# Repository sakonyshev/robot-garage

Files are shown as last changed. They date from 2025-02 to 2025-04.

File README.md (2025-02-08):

# Automatic Vacuum Cleaner Robot Garage  

## Overview  
This project was inspired by the challenge of limited space in an apartment. Dedicating a full square meter of floor space for a robot vacuum’s parking spot seemed inefficient. Instead, the idea was to create a niche under the kitchen cabinets where the robot could park and charge.  

Work

## Features  
- Designed to fit under kitchen cabinets  
- Automatic door mechanism to enclose the robot when parked  
- Provides a dedicated charging space  

## Disclaimer  
⚠ **This is an early-stage, untested prototype.** Any modifications, builds, or implementations based on this project are done **at your own risk**. At the moment, the code only handles opening the door and closing it when the robot returns. The logic is as simple as possible, but the board's capabilities can be expanded. There is an additional slot for an extra sensor. The NodeMCU board has built-in Wi-Fi, so you can set up integration with your server or a virtual assistant such as Alice, Siri, etc.

## Installation & Assembly  
1. **Build the garage frame**  
   - Construct a housing that fits under your kitchen cabinets and accommodates your specific robot vacuum.  
   - Dimensions are **not provided**, as different robot models require different clearance and space. Ensure there is enough room for smooth docking and undocking.  

2. **Add the control board**
   - Prepare **[control board](pcb/board.dip)** based on **NodeMCU** to handle the opening and closing of the garage door. 
   - PCB
   - The control board will manage the door mechanism and control the motor based on signals, such as when the robot leaves and enters the garage.  

3. **Print and install the door mechanism**  
   - Download and 3D print the **gear assembly** responsible for opening and closing the garage door.  
   - The mechanism should be mounted on the **front left wall** of the garage.  
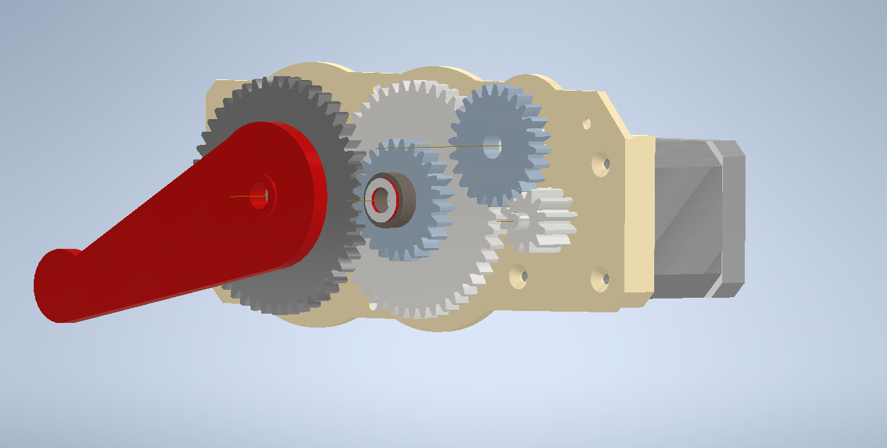
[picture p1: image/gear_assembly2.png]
Gear Assembly
   -   

4. **Install the door panel**  
   - Use a **standard chipboard (DSP) panel** as the door.  
   - Cut it to fit the gap between the **floor and kitchen cabinets**.
   - To create an opening mechanism, use the smallest and simplest hinges that fit your specific setup. Choose compact hinges that provide smooth movement while maintaining durability.
   - Ensure the panel moves freely with the installed gear mechanism.
   -  lift_mechanism

5. **Set up the charging station**  
   - Place the charging dock inside the garage.  
   - Ensure the robot can autonomously navigate into the garage and connect to the charger.

6. **Install a force resistor for docking detection**  
   - Attach a **resistor with variable resistance** to the floor under the robot’s wheel.  
   - The resistor should change its resistance when pressure is applied (i.e., when the robot returns to the base).  
   - This will allow the control board to detect when the robot is properly parked and the garage door can be closed.  

## Components  
- NodeMCU  
- NEMA17 stepper motor
- DRV8825 stepper motor driver
- Optocoupler EL817
- Force resistor 10kOm
- Resistors 10kOm and 260Om
- Linear Voltage Regulator L7805CV
- MOSFET Transistor IRLZ34N
- Capacitors 470mF, 0.1mF, 0.33mF
- Connectors KF301-2P
- Breakable Pin Headers
- Dip 3p toggle switch (or you may use wire jumpers instead)
- 12V power supply

## Connectors and Power Supply
The board has several connectors used for connecting peripheral sensors, a motor, and power supply.

- VCC_IN – Power input for the board. I used a 12V power adapter from an old router, but technically, any power supply up to 24V can be used. I recommend checking the datasheets of the components before using a different power source. Also, pay attention to potential heating of electronic components—heat sinks may need to be installed.
- POWER_SW – A connector for end-stop switch that supplies power to the board when activated.
- SPARE_SOCKET – Additional socket for connecting peripherals. For more details, refer to the schematic. It includes a control pin, a 3V pin, and ground.
- START_POS_SW – Output for the limit switch used to calibrate the initial position of the stepper motor.
- RES_IN – Connector for a resistor that changes its resistance depending on the applied pressure.
- J4 – Connector for connecting the stepper motor.

## Future Improvements  
- Enhanced automation for door control  
- Sensor integration with home assistants
- You'll be able to order control board on pcbway soon

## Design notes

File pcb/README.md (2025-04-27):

# Automatic Vacuum Cleaner Robot Garage  

## Version 1 (Smart Control)

### Operation Flow:
1. **Activation**: 
   - The board powers on when the `POWER_SW` limit switch opens
   - Opens the box for the robot vacuum

2. **Cleaning Cycle**:
   - Robot starts cleaning
   - The board establishes connection with the server and subscribes to vacuum robot updates
   - After a predefined time, the box closes automatically

3. **Completion**:
   - When cleaning finishes, the robot sends a completion notification
   - The box opens and waits for the robot's return

4. **Return Home**:
   - When the robot arrives at the base:
     - After a short delay (using pressure sensor data)
     - The board closes the door

## Version 2 (Simplified Control)

### Operation Flow:
1. **Power Management**:
   - `POWER_SW` is used for physical power toggling:
     - Opening the door powers the board
     - Closing the door cuts power

2. **Cleaning Cycle**:
   - Robot starts cleaning
   - Door opens and remains open until robot returns

3. **Completion**:
   - When robot returns to base:
     - Pressure sensor detects presence
     - Board closes the door
     - Power is physically cut by the `POWER_SW` limit switch

## Key Differences

| Feature | Version 1 | Version 2 |
|---|---|---|
| Power Control | Logical | Physical via POWER_SW |
| Door Operation | Timed close during cleaning | Stays open whole cleaning |
| Server Connection| Maintains connection | No server connection |
| Power Off | Software controlled | Physical switch disconnection |

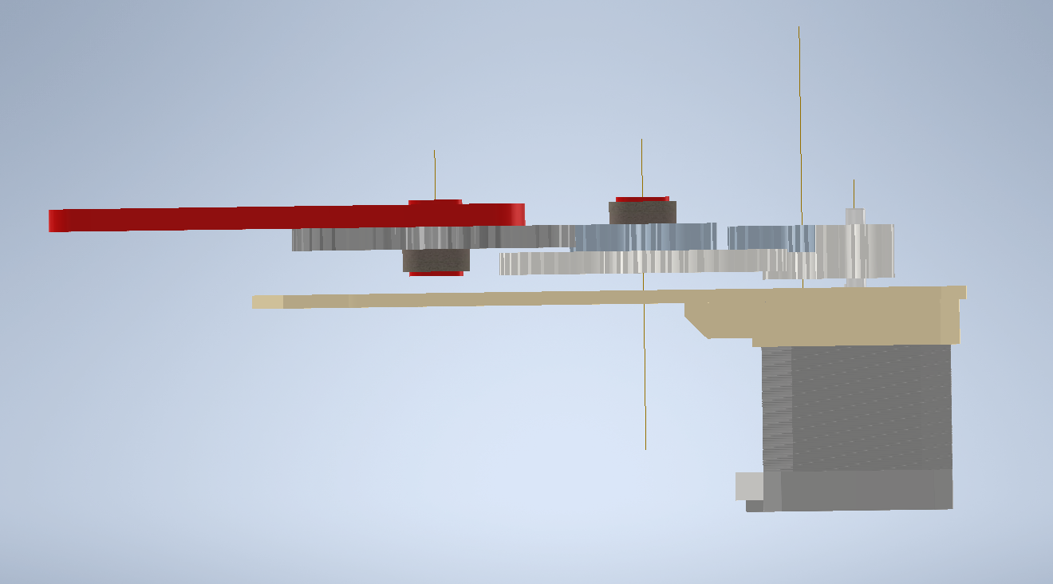
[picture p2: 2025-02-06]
image/bottom_view.png

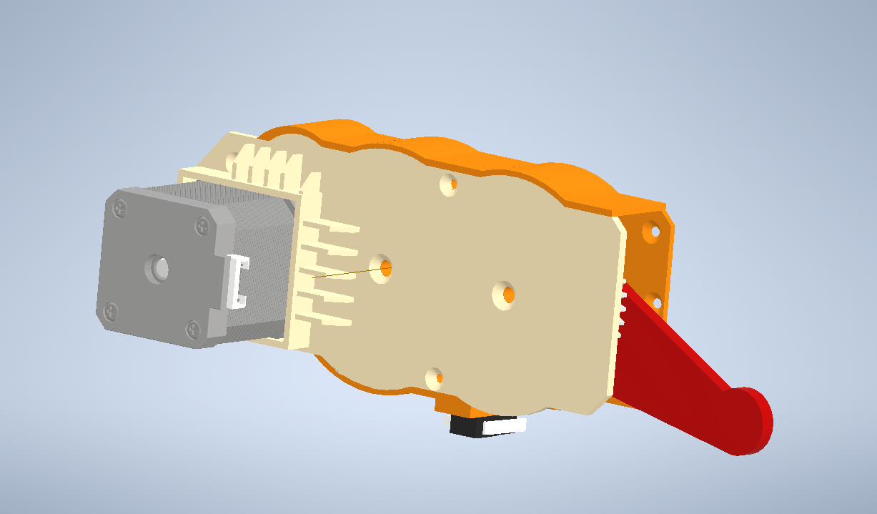
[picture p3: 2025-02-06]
image/main.png

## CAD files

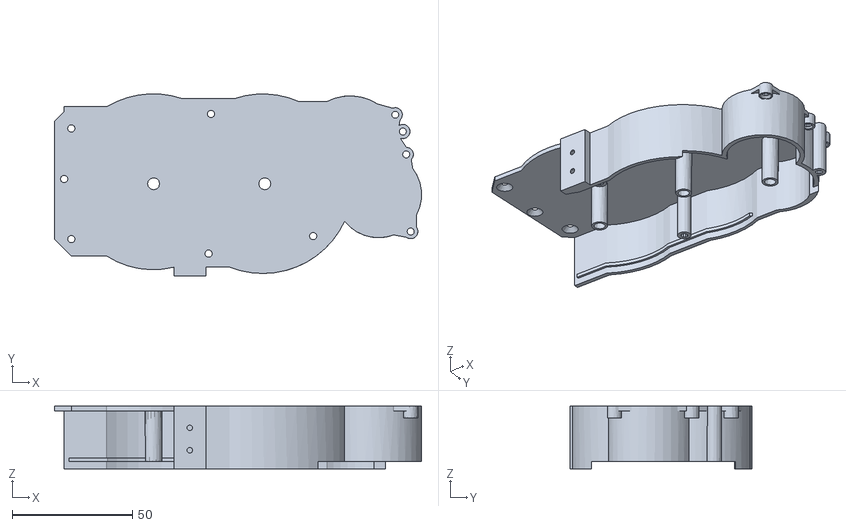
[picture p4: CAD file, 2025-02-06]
model/frame.stl
152.4 x 75.7 x 26.0

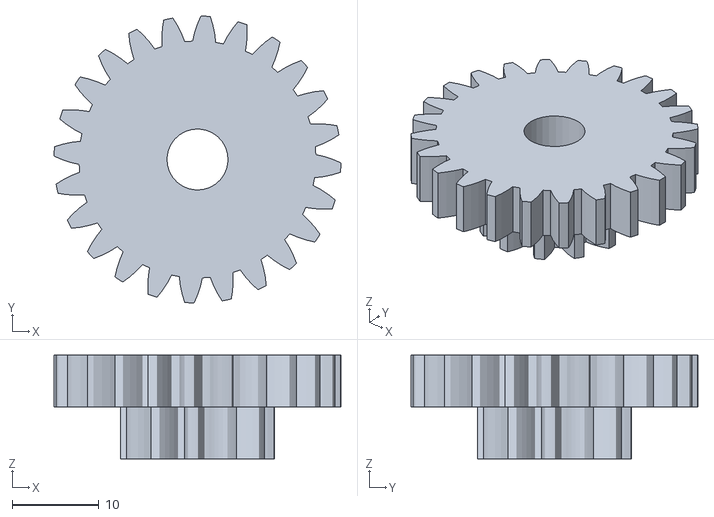
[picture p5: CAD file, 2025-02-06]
model/gearbox/second_gear.stl
33.1 x 33.1 x 12.0

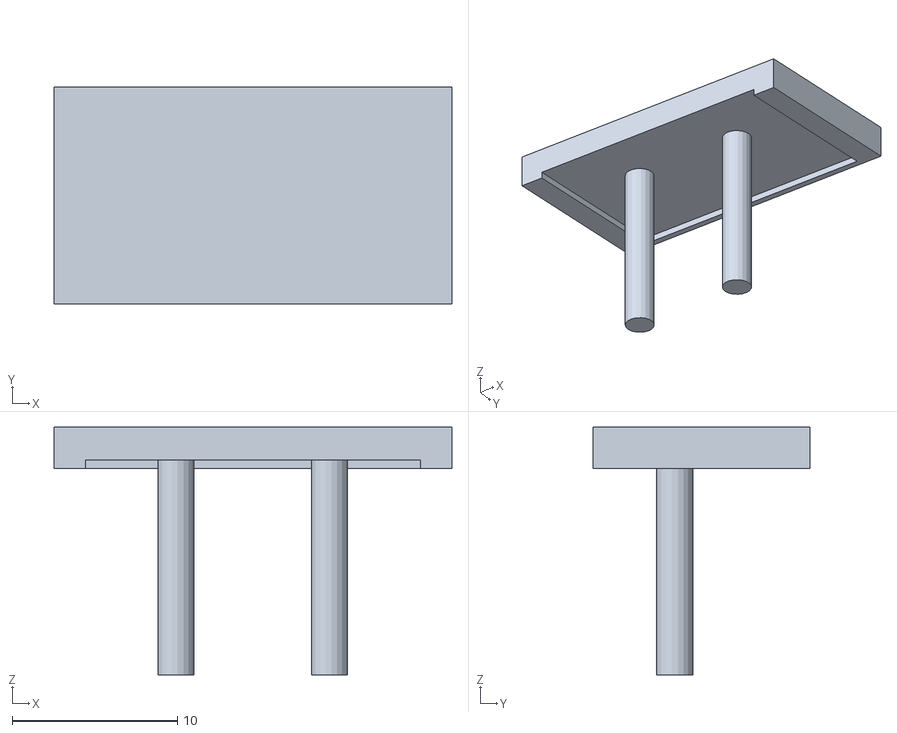
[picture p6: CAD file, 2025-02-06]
model/support/endstop_switcher_mounting.stl
24.1 x 13.1 x 15.0

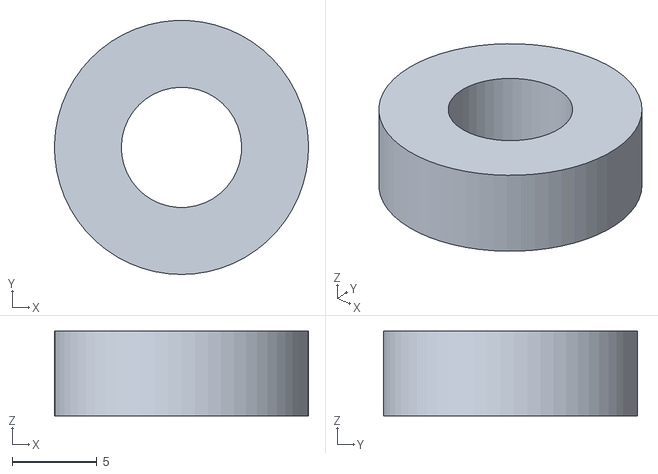
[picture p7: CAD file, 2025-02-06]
model/gearbox/distance_ring.stl
15.0 x 15.0 x 5.00

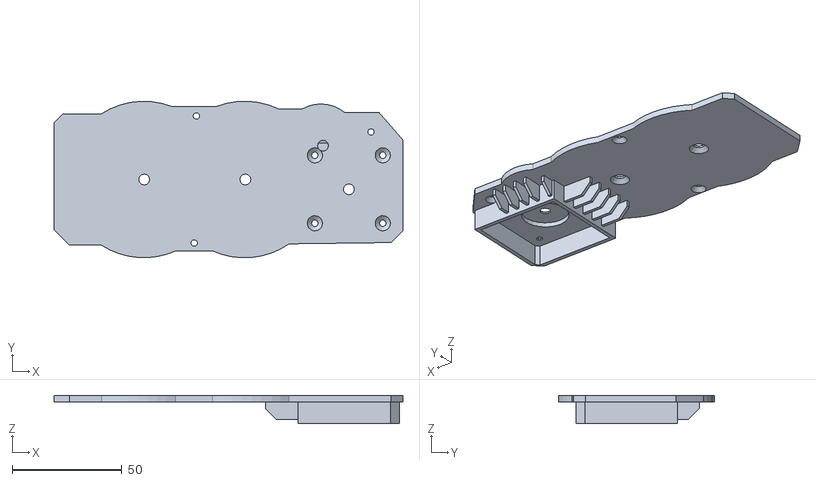
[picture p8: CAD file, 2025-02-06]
model/stepper_motor_holder.stl
159.3 x 71.4 x 13.0

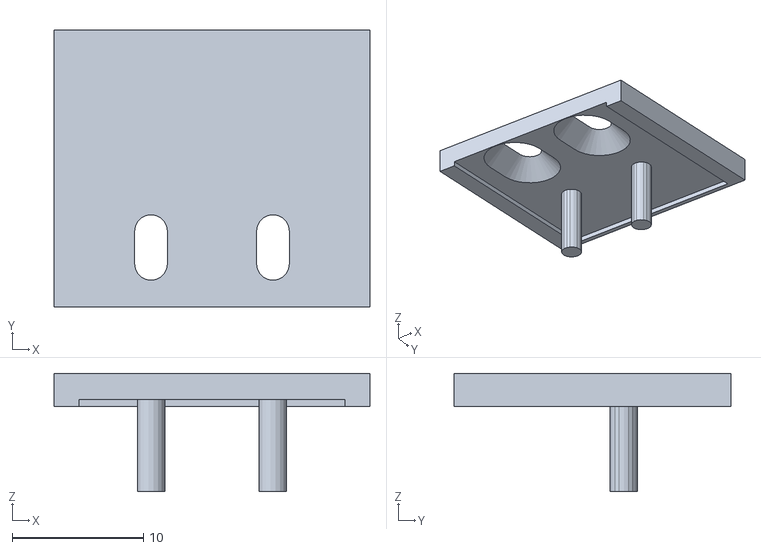
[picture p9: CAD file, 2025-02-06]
model/support/bottom_end_stop_mounting.stl
24.1 x 21.1 x 9.00

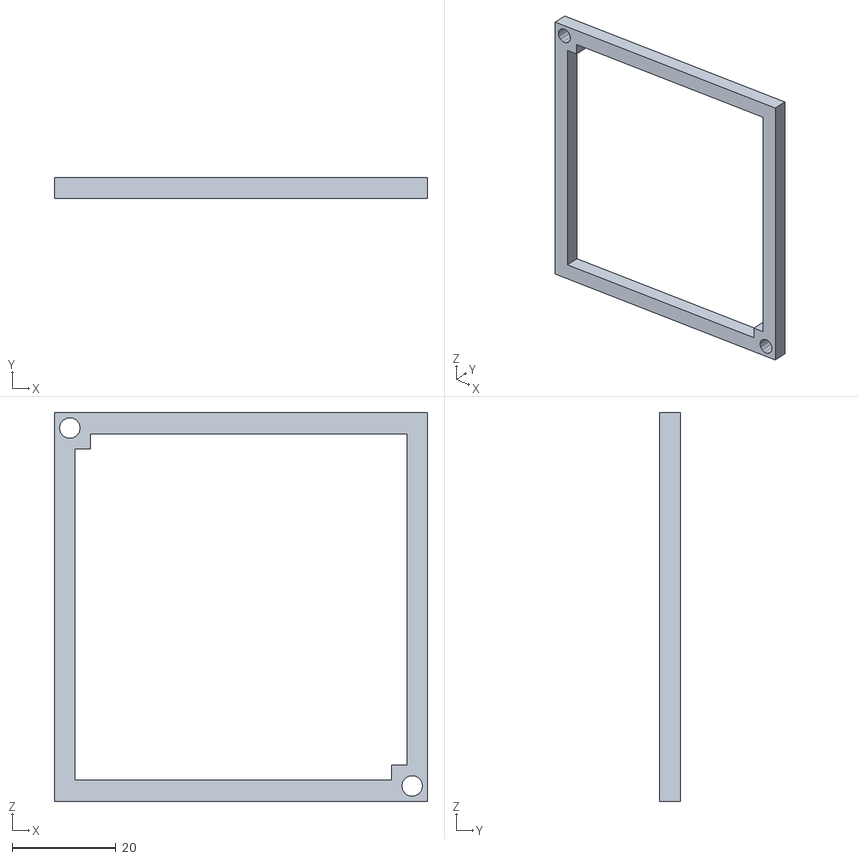
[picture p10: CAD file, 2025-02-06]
model/curcuit_board_mounting_frame.stl
72.0 x 4.00 x 75.0

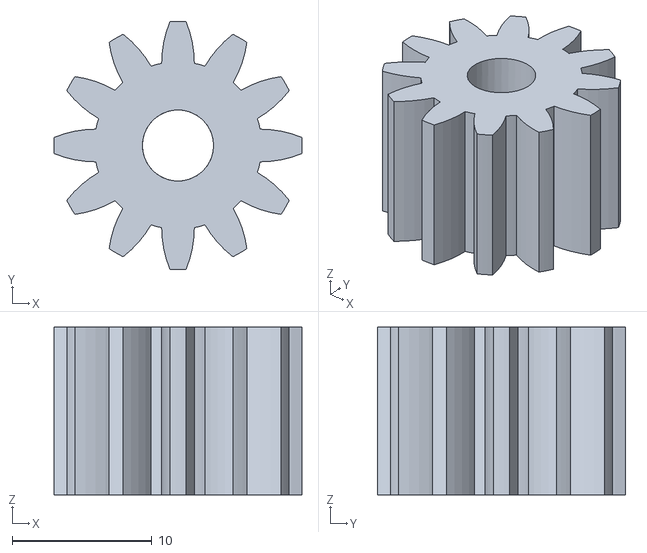
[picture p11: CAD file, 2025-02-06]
model/gearbox/drive_gear.stl
17.8 x 17.8 x 12.0

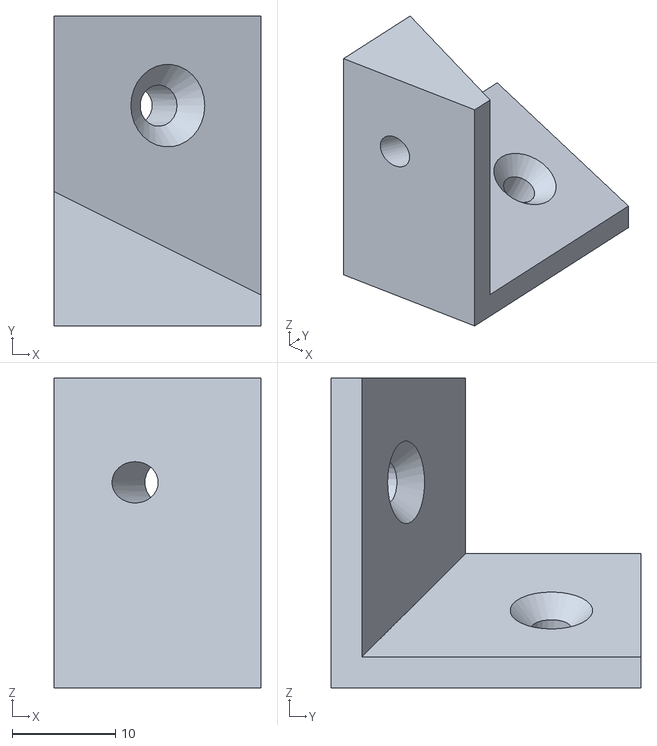
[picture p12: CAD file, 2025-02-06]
model/support/garage_mounting.stl
20.0 x 30.0 x 30.0

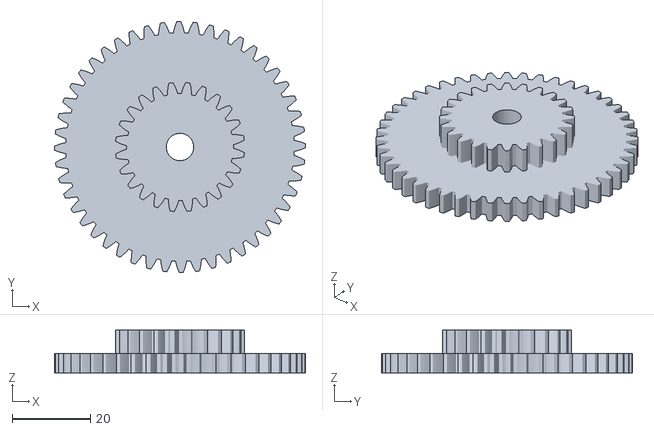
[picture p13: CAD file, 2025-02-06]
model/gearbox/third_gear.stl
64.3 x 64.3 x 11.0

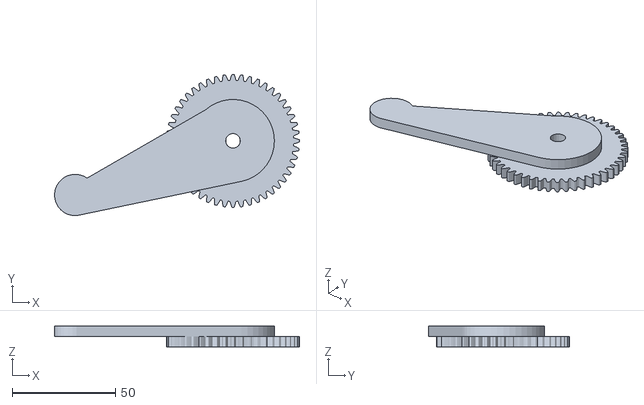
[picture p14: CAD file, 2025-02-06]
model/gearbox/gear_with_lever.stl
118.4 x 68.3 x 10.00

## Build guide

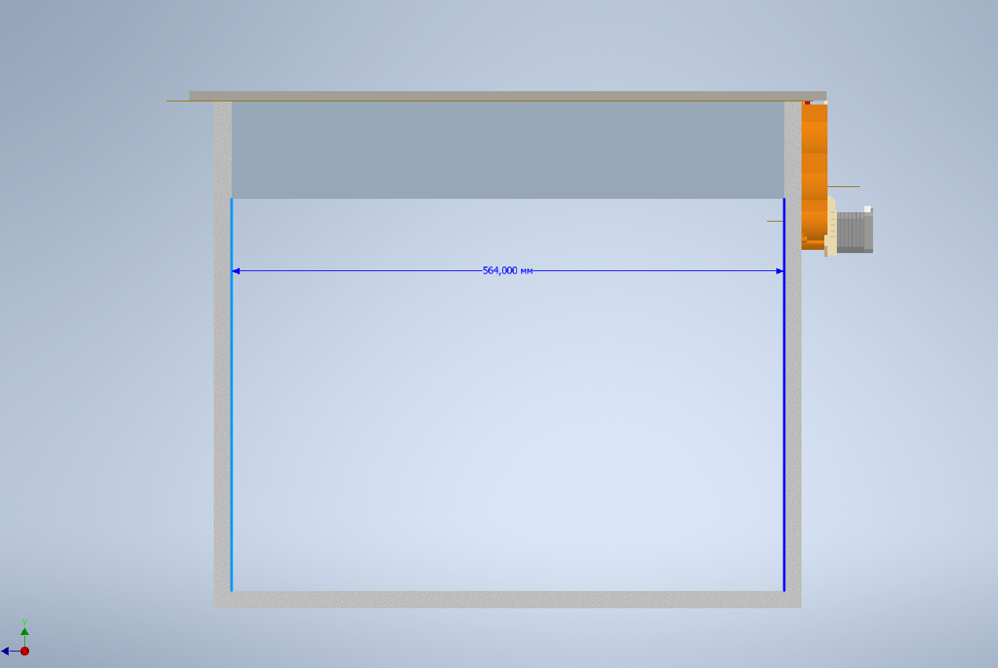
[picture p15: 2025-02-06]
image/garage_assembly_top_view.png

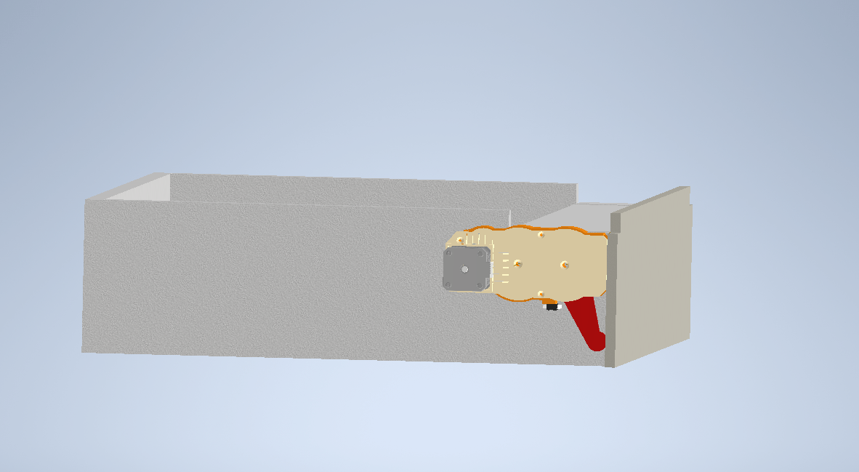
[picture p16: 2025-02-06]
image/garage_assembly_closed_door.png

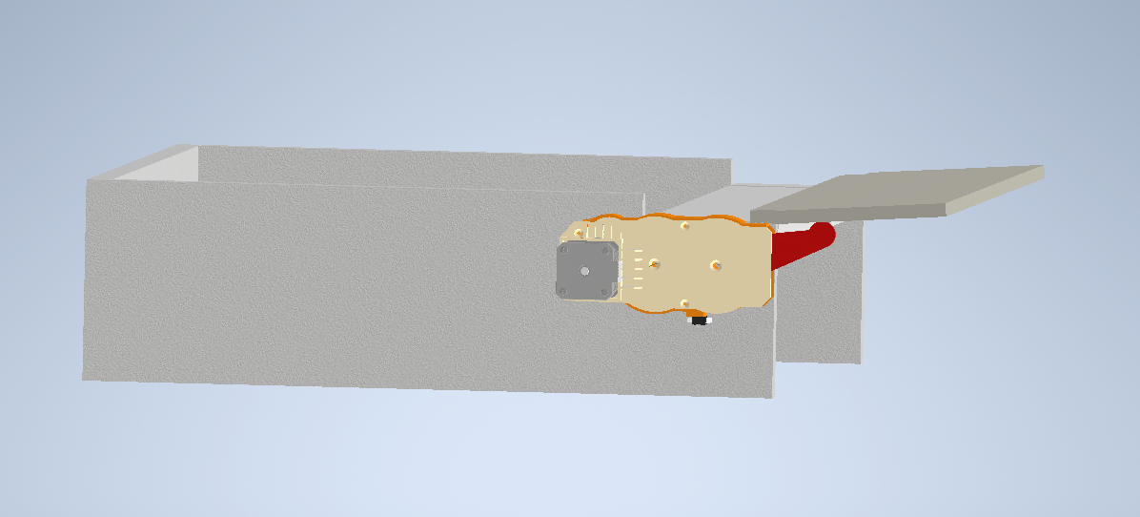
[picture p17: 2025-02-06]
image/garage_assembly_opened_door.png

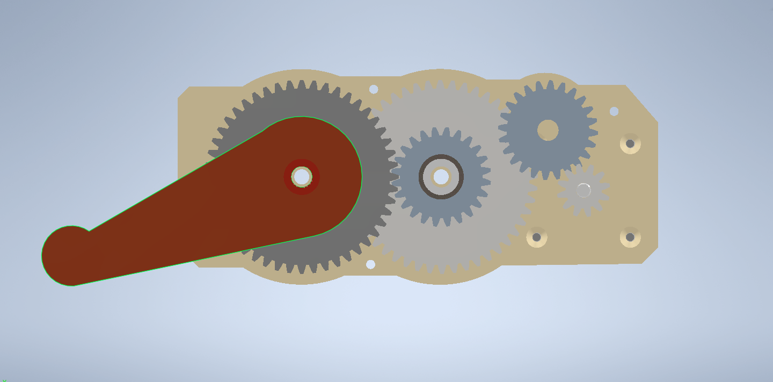
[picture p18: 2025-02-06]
image/gear_assembly.png

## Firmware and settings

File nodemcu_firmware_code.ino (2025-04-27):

#define FORCE_SENSOR_PIN A0 //force resistor pin

// Define stepper motor connections and steps per revolution:
#define enableDriverPin 16 //D0 enable stepper driver
#define dirPin 12 //D6 direction stepper mottor driver pin
#define stepPin 14 //D5 step stepper mottor driver pin

#define enableBoardPin 13  //D7

#define endSwitchStop 5  //D1

#define stepsPerRevolution 1800 * 4

#define default_open_speed 110
#define default_close_speed 220

void setup() {
  //Power on
  pinMode(enableBoardPin, OUTPUT);
  digitalWrite(enableBoardPin, HIGH);
  
  pinMode(enableDriverPin, OUTPUT);
  digitalWrite(enableDriverPin, LOW);

  // Declare pins as output:

  pinMode(stepPin, OUTPUT);
  pinMode(dirPin, OUTPUT);

  // Serial.begin(115200);

  pinMode(endSwitchStop, INPUT);
}

void close(int speed) {
  int stop = 1;

  stop = digitalRead(endSwitchStop);  
  digitalWrite(dirPin, LOW);

  while (stop == 0) {
    digitalWrite(stepPin, HIGH);
    delayMicroseconds(speed);
    digitalWrite(stepPin, LOW);
    delayMicroseconds(speed);

    stop = digitalRead(endSwitchStop);
    yield();
  }
}

void open(int speed) {
  digitalWrite(dirPin, HIGH);

  // // Spin the stepper motor 1 revolution slowly:
  for (int i = 0; i < stepsPerRevolution; i++) {
    // These four lines result in 1 step:
    digitalWrite(stepPin, HIGH);
    delayMicroseconds(speed);
    digitalWrite(stepPin, LOW);
    delayMicroseconds(speed);
    yield();
  }
}

void waitRobotToDock(int docked) {
  
  while (docked != 0) {
    if (analogRead(FORCE_SENSOR_PIN) > 350) {
      docked--;
    }
    delay(2000);
    yield();
    //TODO add change robot position
  }
}


void powerOn() {
  digitalWrite(enableBoardPin, HIGH);
  digitalWrite(enableDriverPin, LOW);
}

void powerOff() {
  digitalWrite(enableDriverPin, HIGH);
  digitalWrite(enableBoardPin, LOW);
  delay(1000);
}

void loop() {
  close(85); //calibrate servo's start position
  open(default_open_speed); //open the garage

  waitRobotToDock(6); //waiting a wheel standing on the force resistor
  close(default_close_speed);
  powerOff();
}

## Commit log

2025-04-27 split board implementation into two versions
2025-04-27 readme for both circuit board versions
